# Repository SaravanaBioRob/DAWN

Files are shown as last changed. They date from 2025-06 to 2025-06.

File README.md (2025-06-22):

# Dual Actuator Wave-Like Navigator (DAWN)

This repository contains the hardware control code, data analysis scripts, and supplementary software used for the development of the **Dual Actuator Wave-Like Navigator (DAWN)** — a soft robotic system that mimics wave-like locomotion.

## 📁 Repository Structure

```
Daul-Actuator-Wave-Like-Navigator/
│
├── design-files/                   # Mechanical and electrical design files
│   ├── molds/                      # STL files for casting robot skin and seal
│   ├── robot/                      # STL and PDF files for mechanical parts and fixtures
│   └── PCB/                        # KiCad PCB layout and schematic files
│
├── data-and-data-analysis/          # MATLAB scripts and live notebooks for data processing
│   ├── *.mlx                        # Live MATLAB analysis (friction, locomotion, wave studies)
│   ├── *.m                          # Script-based versions for data processing and visualization
│   └── data/                        # Experimental datasets (e.g., pressure, force)
│
├── robot-control-code/             # Arduino/mbed code for the main robot controller
│   ├── main.ino                     # Main controller logic (multithreaded tasks with RTOS)
│   ├── motor_control.ino            # Motor operation and state handling
│   ├── pump_control.ino             # Syringe pump actuation commands
│   └── pressure_sensor.ino          # Sensor interface and data capture
│
├── syringe-pump-code/              # Python and Arduino code for pump-side system
│   ├── pressure_sensors_syringe_switches.ino   # Arduino sketch for sensors and switch control
│   └── syringe_datalloging_switches_pressure.py # Python logger and motion driver for syringe pumps
│
└── .git/                            # Git versioning files (ignore)
```

## 🚀 Getting Started

### Hardware Requirements

- Arduino-compatible microcontroller with RTOS support
- Motor drivers and actuators
- Syringe-based pump system
- Pressure sensors and signal conditioning
- Bluetooth/Wireless modules for command/control

### Software Requirements

- [Arduino IDE](https://www.arduino.cc/en/software)
- [MATLAB](https://www.mathworks.com/products/matlab.html)
- Python 3.8+ with packages:
  - `pyserial`, `pandas`, `matplotlib`, `keyboard`, `csv`
  
## 🧩 Design Files

Located in the `design-files/` directory, this folder contains all physical and electronic design assets:

### 🔩 Molds (`design-files/molds/`)
- 3D printable STL files for casting soft robot components
- Includes molds for skin, junction seals, and structural elements

### 🖨️ Robot Parts (`design-files/robot/`)
- STL files for structural components like clamps, links, couplings, and braces
- Includes CAD files for electronics enclosures and laser-cut shapes

### 🧾 Electronics (`design-files/PCB/`)
- KiCad design files (`.kicad_pcb`, `.kicad_sch`) for the component shield PCB
- Backup archives for version control

## 📊 Data Analysis

MATLAB Live Scripts (`.mlx`) allow rich analysis and visualization of robotic behavior:

- `traveling_wave_analysis.mlx`: Wave pattern effectiveness
- `sand_sledge_analysis.mlx`: Sledge study on granular media
- `simple_locomotion_analysis.mlx`: Basic locomotion profiles and analysis
- `friction_analysis.mlx`: Frictional force modeling
- `pressure_analysis_one_cicle.m`: Single-cycle pressure response

## 🔧 Control Code Highlights

- **Multithreading with RTOS:** Used for concurrent sensor reading, motor control, and pump updates.
- **BLE Communication:** Allows for wireless control and data transmission.
- **Pressure Feedback Loop:** Real-time monitoring of actuation pressure to maintain wave shape.

## 📈 Logging & Experiments

The syringe-pump Python script (`syringe_datalloging_switches_pressure.py`) controls movements and logs data over serial. It allows frequency and speed modulation to experiment with various gait cycles.

## 🧪 Example Usage

1. Upload `main.ino` and related `.ino` files to the robot controller.
2. Upload `pressure_sensors_syringe_switches.ino` to Arduino Mega connected to the syringe system.
3. Run the Python logging script to collect data and drive actuation.
4. Analyze results with MATLAB using the provided `.mlx` scripts.

## 📜 License

This project is currently in development and is shared under the MIT License.

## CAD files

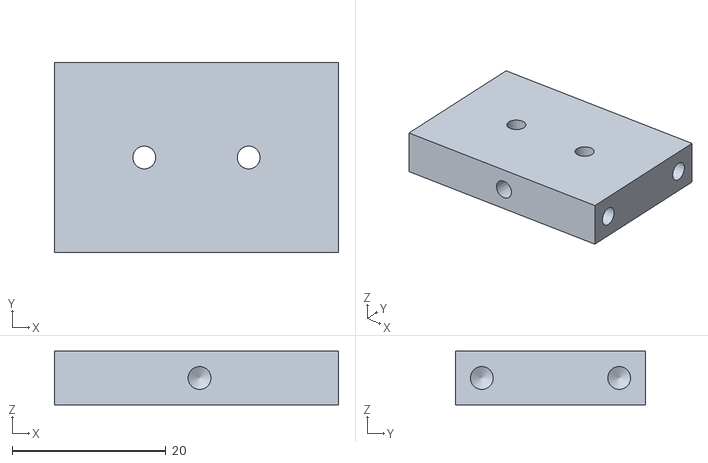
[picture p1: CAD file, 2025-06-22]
design-files/molds/Mold_skin_BackWall.stl
37.0 x 24.8 x 7.00

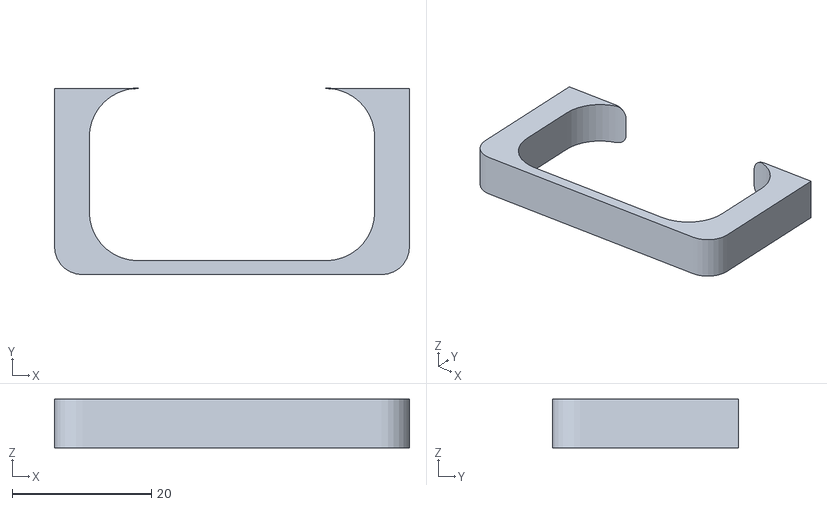
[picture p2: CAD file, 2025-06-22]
design-files/robot/Clamp.stl
51.0 x 26.8 x 7.00

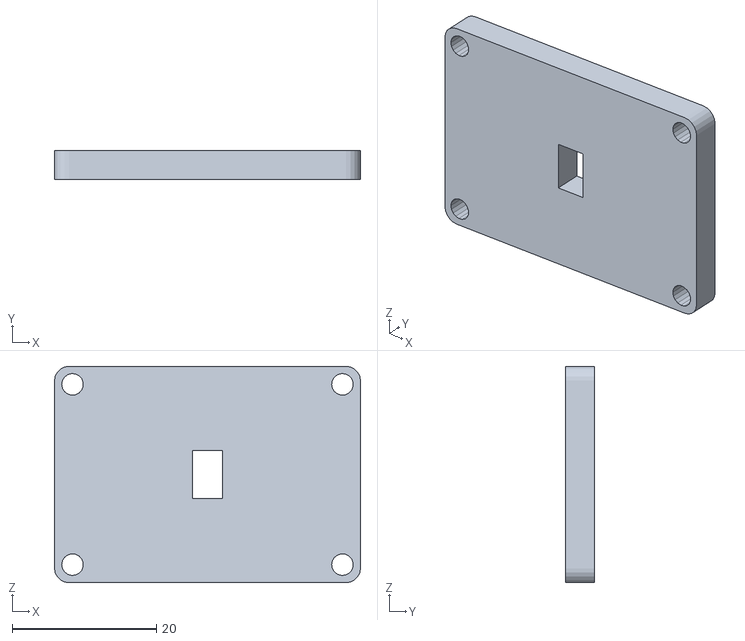
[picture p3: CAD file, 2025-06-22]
design-files/molds/Mold_junction_seal_lid.stl
42.4 x 4.00 x 30.0

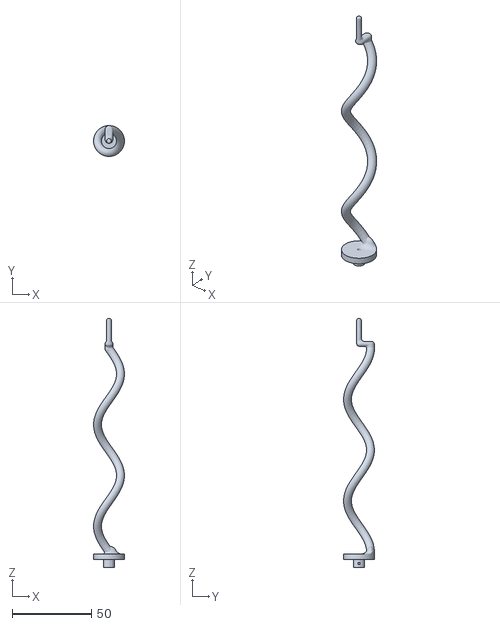
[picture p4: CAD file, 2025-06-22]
design-files/robot/Helix.stl
19.5 x 19.5 x 157.0

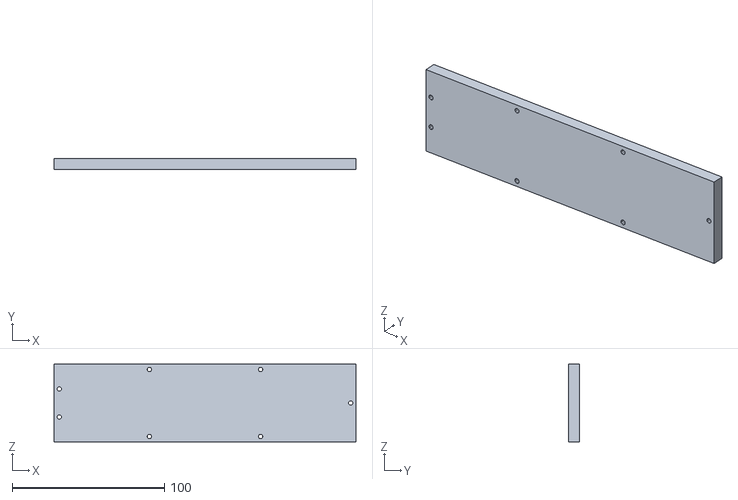
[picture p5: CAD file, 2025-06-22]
design-files/molds/Mold_skin_Bottom.stl
198.3 x 7.00 x 51.0

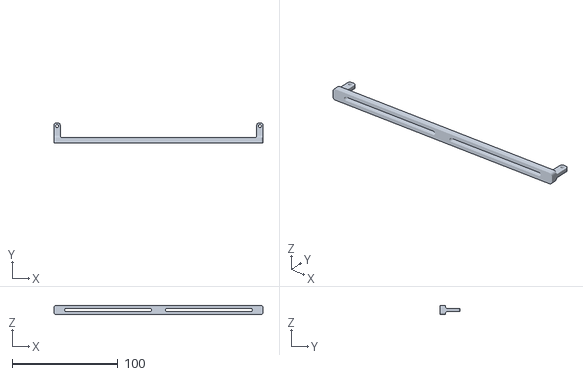
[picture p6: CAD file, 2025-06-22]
design-files/robot/Brace_slide.stl
198.1 x 19.0 x 9.00

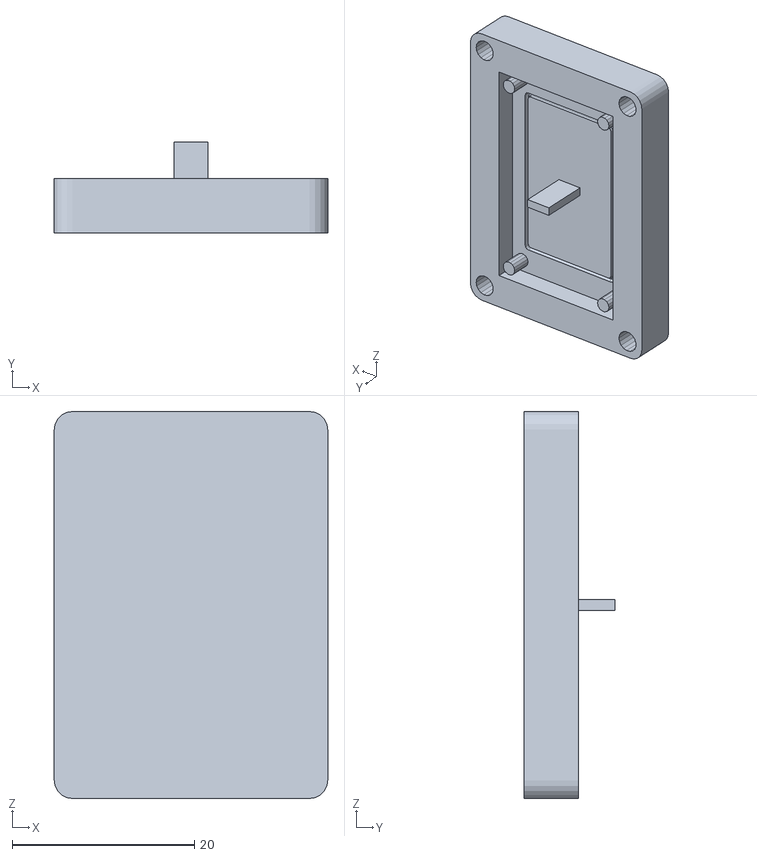
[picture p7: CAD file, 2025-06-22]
design-files/molds/Mold_junction_seal_base.stl
30.0 x 10.0 x 42.4

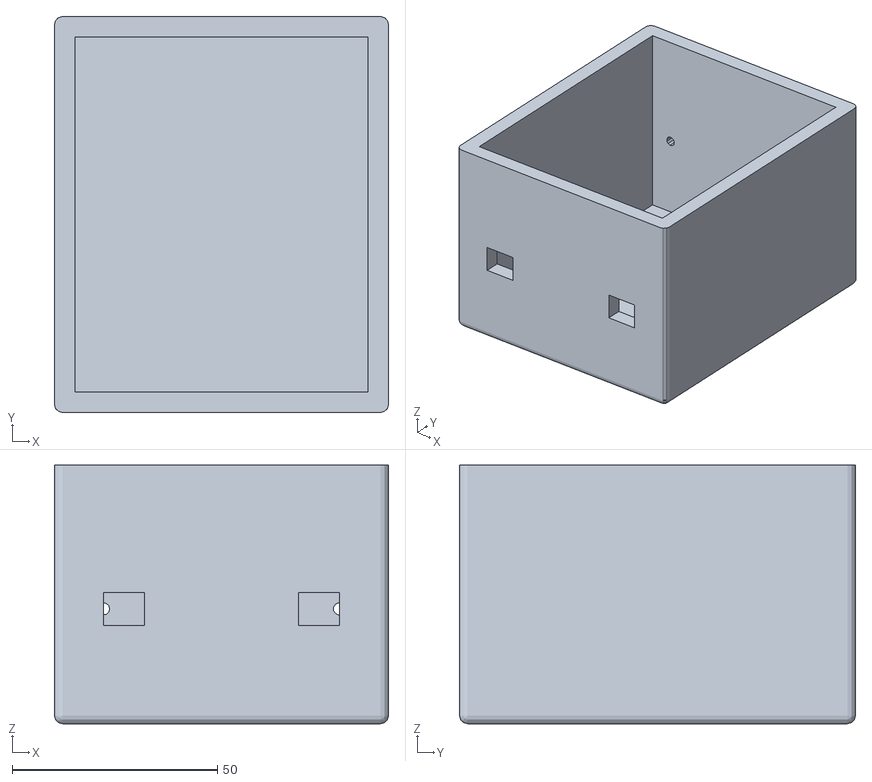
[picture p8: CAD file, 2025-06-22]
design-files/robot/electronics_enclosure.stl
81.4 x 96.5 x 63.0

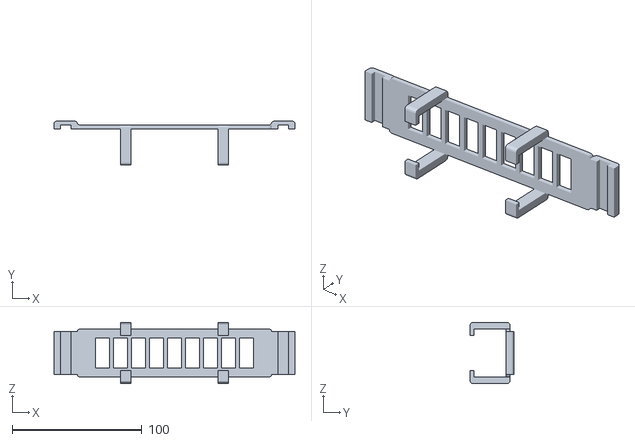
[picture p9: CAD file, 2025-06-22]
design-files/molds/Dual_lock_stencil.stl
185.5 x 33.8 x 47.0

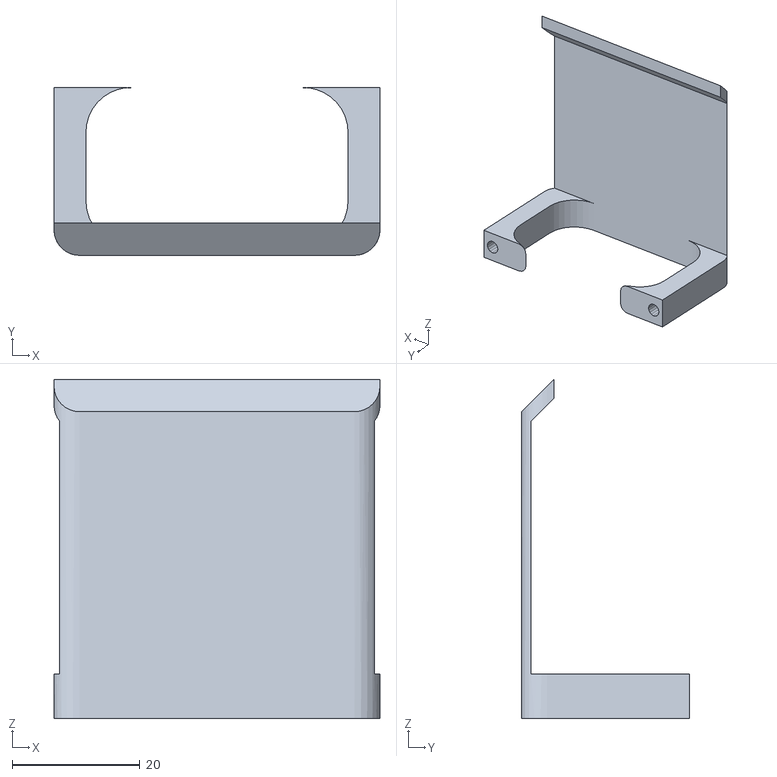
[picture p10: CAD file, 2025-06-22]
design-files/robot/Clamp_sledge.stl
51.0 x 26.2 x 53.0

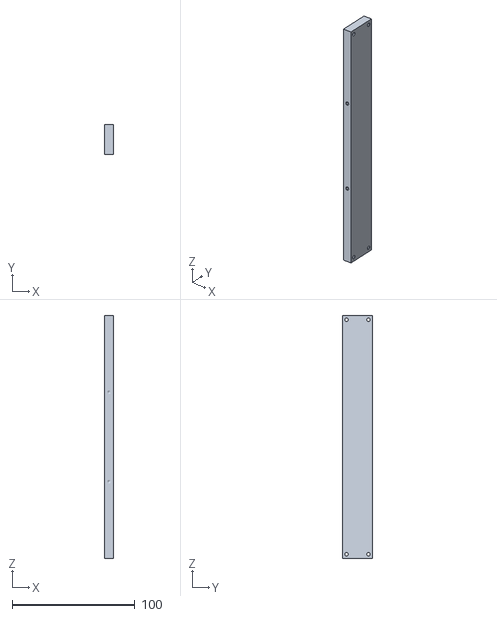
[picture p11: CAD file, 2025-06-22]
design-files/molds/Mold_skin_sideWall.stl
7.00 x 24.8 x 198.3

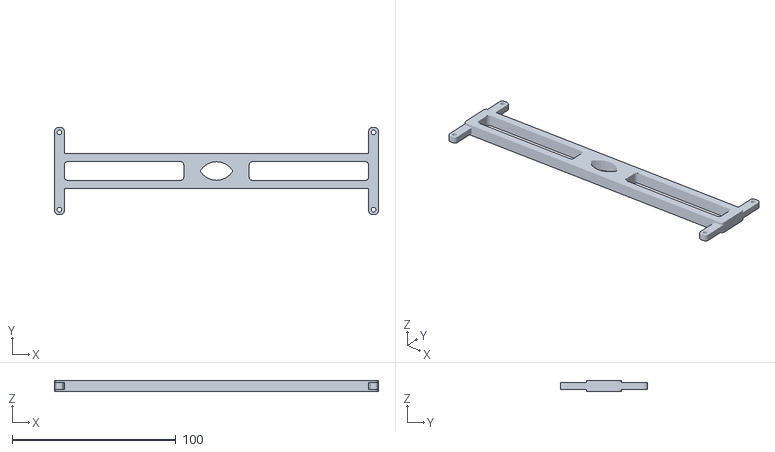
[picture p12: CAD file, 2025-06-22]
design-files/robot/Brace_middle.stl
198.1 x 53.2 x 7.00

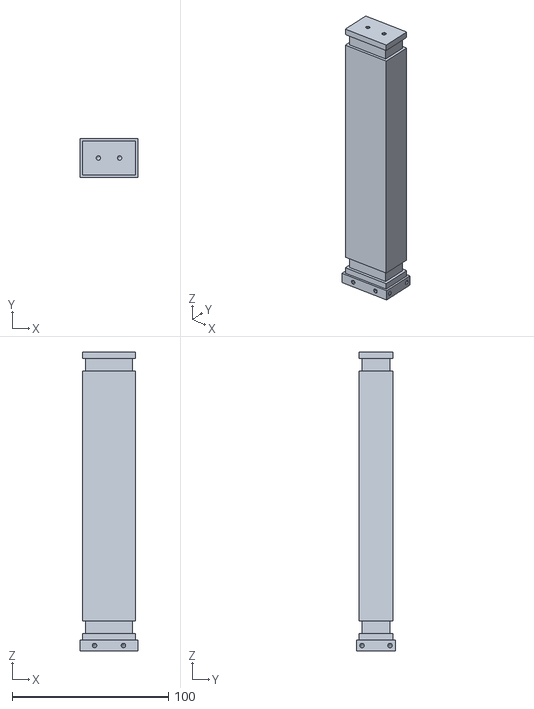
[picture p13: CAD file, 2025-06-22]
design-files/molds/Mold_skin_Shaft.stl
37.0 x 24.8 x 191.3

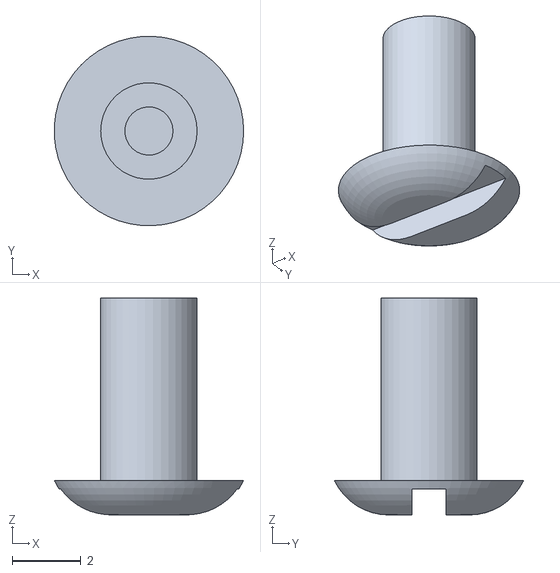
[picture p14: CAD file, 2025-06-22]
design-files/robot/link_binding_post_long.stl
5.50 x 5.50 x 6.30

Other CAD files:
design-files/robot/PCB_mounting_plate.stl
design-files/robot/link_binding_post_shim.stl
design-files/robot/Clamp_top.stl
design-files/robot/link_binding_post.stl
design-files/robot/Brace_unequal.stl
design-files/robot/DAWN_chain.stl
design-files/robot/DAWN_motor_coupling.stl
design-files/robot/DAWN_motor_coupling_mirror.stl
design-files/robot/Junction_plate.stl
design-files/robot/Pneumatic_coupling.stl
design-files/robot/electronics_enclosure_bottom.stl
design-files/robot/link.stl

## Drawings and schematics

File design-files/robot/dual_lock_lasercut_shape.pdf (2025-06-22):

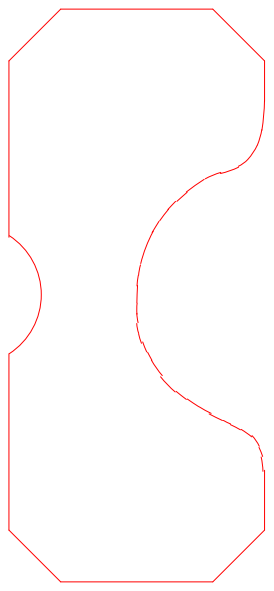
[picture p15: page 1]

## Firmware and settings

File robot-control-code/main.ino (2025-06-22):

#include <mbed.h>
#include <ArduinoBLE.h>
#include "Arduino_BMI270_BMM150.h"

using namespace mbed;
using namespace rtos;
 
using namespace std::chrono_literals;

bool runCue = 0;

Queue<uint8_t,32> motorServiceQueue;
Queue<int,32> pumpServiceQueue;
Queue<bool,16> pressureServiceRXQueue;
Queue<int,128> pressureServiceTXQueue;
Queue<double,128> pressureLQueue;
Queue<double,128> pressureRQueue;

Semaphore motorServiceQueueSemaphore(1);
Semaphore pumpServiceQueueSemaphore(1);
Semaphore pressureServiceRXQueueSemaphore(1);
Semaphore pressureServiceTXQueueSemaphore(1);
Semaphore pressureLQueueSemaphore(1);
Semaphore pressureRQueueSemaphore(1);
Semaphore runCueSemaphore(1);

Thread t1;
Thread t2;
Thread t3;
Thread t4;
Thread t5;

void setup() {
  Serial.begin(9600);
  //while (!Serial);

  // set LED's pin to output mode
  pinMode(LEDR, OUTPUT);
  pinMode(LEDG, OUTPUT);
  pinMode(LEDB, OUTPUT);
  pinMode(LED_BUILTIN, OUTPUT);

  digitalWrite(LED_BUILTIN, LOW);         // when the central disconnects, turn off the LED
  digitalWrite(LEDR, HIGH);               // will turn the LED off
  digitalWrite(LEDG, HIGH);               // will turn the LED off
  digitalWrite(LEDB, HIGH);                // will turn the LED off

  bluetooth_init();

  if (!IMU.begin()) {
    Serial.println("Failed to initialize IMU!");
    while (1);
  }

  Serial.print("Accelerometer sample rate = ");
  Serial.print(IMU.accelerationSampleRate());
  Serial.println("Hz");

  t1.start(TaskBluetooth);
  t2.start(TaskMotorControl);
  t3.start(TaskPumpControl);
  t4.start(TaskPressureSense);
  //t5.start(TaskPosition);
}
void loop() {
  
}

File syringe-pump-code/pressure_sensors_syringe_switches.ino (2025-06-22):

#define SWITCH_PIN 22  // The pin where the switch is connected

void setup() {
  Serial.begin(9600);
  pinMode(SWITCH_PIN, INPUT_PULLUP);  // Enable internal pull-up resistor
}

void loop() {
  int raw1 = analogRead(A0);
  int raw2 = analogRead(A1);

  float pressure1 = (raw1 * 5.0 / 1023.0 - 0.5) * 25.0;
  float pressure2 = (raw2 * 5.0 / 1023.0 - 0.5) * 25.0;

  // Read switch state (LOW when pressed, HIGH when open)
  int switchState = digitalRead(SWITCH_PIN);

  // Send as CSV: timestamp, pressure1, pressure2, switchState
  Serial.print(millis());
  Serial.print(",");
  Serial.print(pressure1);
  Serial.print(",");
  Serial.print(pressure2);
  Serial.print(",");
  Serial.println(switchState);  // 0 when pressed, 1 when open

  delay(10);  // 100 Hz
}

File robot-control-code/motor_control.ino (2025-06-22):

#include <Servo.h>
#include <mbed.h>
 
using namespace mbed;
using namespace rtos;
 
using namespace std::chrono_literals;

extern bool runCue;
extern Queue<uint8_t,32> motorServiceQueue;
extern Semaphore motorServiceQueueSemaphore;
extern Semaphore runQue;

#define speed_maxP 0 //Clockwise rotation (Max speed)
#define speed_maxN 180 //Anticlockwise rotation (Max speed)
#define speed_stop 90 //Stop
double left_scaling_factor = 1.20;

Servo motorLeft;
Servo motorRight;

void TaskMotorControl()  // This is a Task.
{
  motorRight.attach(10);
  motorLeft.attach(9);
  uint8_t motorControlInput = 5;
  uint8_t motorControlInputOld = 5;
  uint8_t* motorControlInput_p;

  uint8_t leftadjust = 0;
  uint8_t rightadjust = 0;

  while(1)
  {
    if(motorServiceQueue.try_get(&motorControlInput_p)){
      motorControlInput = *motorControlInput_p;
      delete motorControlInput_p;
    }

    bool cue = 0;
    if(motorControlInput != 5)
      cue = 1;

    runCueSemaphore.try_acquire();
    runCue = cue;
    runCueSemaphore.release();

    if(motorControlInput == 10)
    {
      if(rightadjust == 0)
        leftadjust += 5;
      else
        rightadjust -= 5;
      motorControlInput = motorControlInputOld;
    }
    if(motorControlInput == 12)
    {
      if(leftadjust == 0)
        rightadjust +=5;
      else
        leftadjust -= 5;
      motorControlInput = motorControlInputOld;
    }
    if(motorControlInput == 13)
    {
      if(rightadjust == 0)
        leftadjust += 10;
      else
        rightadjust -= 10;
      motorControlInput = motorControlInputOld;
    }
    if(motorControlInput == 15)
    {
      if(leftadjust == 0)
        rightadjust += 10;
      else
        leftadjust -= 10;
      motorControlInput = motorControlInputOld;
    }
    if(motorControlInput == 11)
    {
      leftadjust = 0;
      rightadjust = 0;
      motorControlInput = motorControlInputOld;
    }

    switch(motorControlInput)
    {
      case 1:
        //Serial.println("Long Curve Back Left");
        motorLeft.write(speed_stop);
        motorRight.write(speed_maxN);
        break;
      case 2:
        //Serial.println("Back");
        motorLeft.write(speed_maxN*left_scaling_factor - leftadjust);
        motorRight.write(speed_maxN - rightadjust);
        break;
      case 3:
        //Serial.println("Long Curve Back Right");
        motorLeft.write(speed_maxN);
        motorRight.write(speed_stop);
        break;
      case 4:
        //Serial.println("Differential Left");
        motorLeft.write(speed_maxN);
        motorRight.write(speed_maxP);
        break;
      case 5:
        Serial.println("Stop");
        motorLeft.write(speed_stop);
        motorRight.write(speed_stop);
        break;
      case 6:
        //Serial.println("Differential Right");
        motorLeft.write(speed_maxP);
        motorRight.write(speed_maxN);
        break;
      case 7:
        //Serial.println("Long Curve Forward Left");
        motorLeft.write(speed_stop);
        motorRight.write(speed_maxP);
        break;
      case 8:
        Serial.println("Forward");
        motorLeft.write(speed_maxP*left_scaling_factor - leftadjust);
        motorRight.write(speed_maxP - rightadjust);
        break;
      case 9:
        //Serial.println("Long Curve Forward Right");
        motorLeft.write(speed_maxP);
        motorRight.write(speed_stop);  
        break;
    }

    motorControlInputOld = motorControlInput;
    
    ThisThread::sleep_for(250ms);  // wait 250 ms
  }
}

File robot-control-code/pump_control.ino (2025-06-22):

#include <mbed.h>
 
using namespace mbed;
using namespace rtos;
 
using namespace std::chrono_literals;

extern Queue<int,32> pumpServiceQueue;
extern Semaphore pumpServiceQueueSemaphore;
extern Queue<double,128> pressureLQueue;
extern Queue<double,128> pressureRQueue;
extern Semaphore pressureLQueueSemaphore;
extern Semaphore pressureRQueueSemaphore;

#define PIN_pump 8
#define PIN_inlet_valve A4
#define PIN_outlet_valve A5
#define PIN_skin_valveL 6
#define PIN_skin_valveR 7

#define idle_state 0
#define operate_state 1

#define inflate_signal 14
#define deflate_signal 13 // placeholders at the moment
#define idle 0

void pump(PinStatus status) ///<Pump operation
{
 digitalWrite(PIN_pump,status);
}

void inflate(uint8_t side)
{
  digitalWrite(PIN_inlet_valve,HIGH);
  digitalWrite(PIN_outlet_valve,HIGH);
  digitalWrite(side,LOW);
  digitalWrite(PIN_pump,HIGH);
}

void deflate(uint8_t side)
{
  digitalWrite(PIN_inlet_valve,LOW);
  digitalWrite(PIN_outlet_valve,LOW);
  digitalWrite(side,HIGH);
  digitalWrite(PIN_pump,HIGH);
}

void stop(uint8_t side)
{
  digitalWrite(PIN_inlet_valve,LOW);
  digitalWrite(PIN_outlet_valve,LOW);
  digitalWrite(side,LOW);
  digitalWrite(PIN_pump,LOW);
}

class ThreeStateController {
public:
    // Constructor that sets the target and tolerance values
    ThreeStateController(uint8_t target, double tolerance)
        : target(target), tolerance(tolerance) {}

    void changeSetpoint(double nSetpoint) {
        setpoint = nSetpoint;
    }

    // Control function that returns "inflate", "deflate", or "stop"
    void control(double measured_value) {
        if (measured_value < setpoint - tolerance) {
            inflate(target);
        } else if (measured_value > setpoint + tolerance) {
            deflate(target);
        } else {
            stop(target);
        }
    }

private:
    uint8_t target;   // Skin to inflate
    double tolerance;  // Allowed tolerance around the setpoint
    double setpoint;
};

class BangBangController {
public:
    // Constructor takes in the target setpoint
    BangBangController(double tolerance) : tolerance(tolerance) {}

    void changeSetpoint(double target) {
      setpoint = target;
    }

    // Control function: returns 1 if below setpoint, 0 if at or above setpoint
    void control(double measured_value) {
        if (measured_value < setpoint) {
            digitalWrite(PIN_pump,HIGH);  // Turn on
        } else {
            digitalWrite(PIN_pump,LOW);  // Turn off
        }
    }

private:
    double tolerance; // Allowed tolerance around the setpoint
    double setpoint;
};

void TaskPumpControl()  // This is a Task.
{
  pinMode(PIN_pump, OUTPUT);
  pinMode(PIN_inlet_valve, OUTPUT);
  pinMode(PIN_outlet_valve, OUTPUT);
  pinMode(PIN_skin_valveL, OUTPUT);
  pinMode(PIN_skin_valveR, OUTPUT);

  int pumpControlInput = 0;
  int* pumpControlInput_p;
  double pressureL = 0;
  double* pressureL_p;
  double pressureR = 0;
  double* pressureR_p;

  double tolerance = 5.0;

  ThreeStateController Lcontroller(PIN_skin_valveL,tolerance);
  ThreeStateController Rcontroller(PIN_skin_valveR,tolerance);
  BangBangController controller(tolerance);

  while(1)
  {
    if(pumpServiceQueueSemaphore.try_acquire()){
      if(pumpServiceQueue.try_get(&pumpControlInput_p)){
        pumpControlInput = *pumpControlInput_p;
        delete pumpControlInput_p;
      }
      //Serial.println(pumpControlInput);
      controller.changeSetpoint(pumpControlInput);
      pumpServiceQueueSemaphore.release();
    }

    if(pressureLQueueSemaphore.try_acquire()){
      if(pressureLQueue.try_get(&pressureL_p)){
        pressureL = *pressureL_p;
        delete pressureL_p;
      }
      pressureLQueueSemaphore.release();
    }

    if(pressureRQueueSemaphore.try_acquire()){
      if(pressureRQueue.try_get(&pressureR_p)){
        pressureR = *pressureR_p;
        delete pressureR_p;
      }
      pressureRQueueSemaphore.release();
    }

    controller.control(pressureL);
    controller.control(pressureR);

    ThisThread::sleep_for(50ms); //sleep for 50 ms
  }
}

/*
void TaskPumpControl()  // This is a Task.
{
  pinMode(PIN_pump, OUTPUT);
  pinMode(PIN_inlet_valve, OUTPUT);
  pinMode(PIN_outlet_valve, OUTPUT);
  pinMode(PIN_skin_valve, OUTPUT);

  uint8_t pump_state = idle_state;
  uint8_t pumpControlInput = 0;
  uint8_t* pumpControlInput_p;

  while(1)
  {
    if(pumpServiceQueueSemaphore.try_acquire()){
      if(pumpServiceQueue.try_get(&pumpControlInput_p)){
        pumpControlInput = *pumpControlInput_p;
        delete pumpControlInput_p;
      }
      pumpServiceQueueSemaphore.release();
    }
    //Serial.println(pumpControlInput);
    
    switch (pump_state)
    {
      case idle_state:

        if(pumpControlInput == inflate)
        {
          //Serial.println("Inflate");
          digitalWrite(PIN_inlet_valve,HIGH);
          digitalWrite(PIN_outlet_valve,HIGH);
          digitalWrite(PIN_skin_valve,LOW);
          digitalWrite(PIN_pump,HIGH);
          pump_state = operate_state;
        }
          
        if(pumpControlInput == deflate)
        {
          //Serial.println("Deflate");
          digitalWrite(PIN_inlet_valve,LOW);
          digitalWrite(PIN_outlet_valve,LOW);
          digitalWrite(PIN_skin_valve,HIGH);
          pump(HIGH);
          pump_state = operate_state;
        }
        
        break;

      case operate_state:

        if(pumpControlInput == idle)
        {
          //Serial.println("Idle");
          digitalWrite(PIN_inlet_valve,LOW);
          digitalWrite(PIN_outlet_valve,LOW);
          digitalWrite(PIN_skin_valve,LOW);
          pump(LOW);
          pump_state = idle_state;
        }

        break;
    }

    ThisThread::sleep_for(50ms); //sleep for 50 ms
  }
}
*/

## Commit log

2025-06-22 data and data analysis added
    [exp1_dynamic_skin.csv, exp1_dynamic_skinless.csv, exp1_static_skinless.csv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]
2025-06-22 syringe pump code added
2025-06-22 design files added
    [Brace_middle.stl, Brace_slide.stl, Brace_unequal.stl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]
